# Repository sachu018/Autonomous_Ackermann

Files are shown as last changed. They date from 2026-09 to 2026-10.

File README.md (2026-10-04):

# Design, Real-Time Embedded Control & Autonomous Navigation for an Agricultural Ackermann Rover





[]()

> **Internship Project Report & Engineering Handover**  
> **Author:** Jagan J S (*Embedded Engineering Intern, Department of Electrical Engineering, IIT Palakkad*)  
> **Project:** *Aerial Dexterous Manipulators, Grasping and Transportation / Autonomous Agricultural Robotics*  
> **Documentation:** 📄 [Internship Report (PDF)](docs/Internship_Report.pdf) | 📘 [Handover Document (PDF)](docs/Handover_Document.pdf) | 📋 [Technical Handover Guide (MD)](docs/SUCCESSOR_HANDOVER_GUIDE.md)

---

## 📌 Executive Summary

Modern precision agriculture relies on autonomous unmanned ground vehicles (UGVs) to execute labour-intensive field tasks such as row monitoring, precision spraying, and selective weeding. 

This repository houses the complete electrical architecture, bare-metal C firmware, PCB design files, and Python autonomy stack developed to transform a legacy, open-loop BeagleBone Black differential-drive rover into a distributed, closed-loop **STM32F411 + Raspberry Pi 5 Ackermann-steering autonomous agricultural rover**.

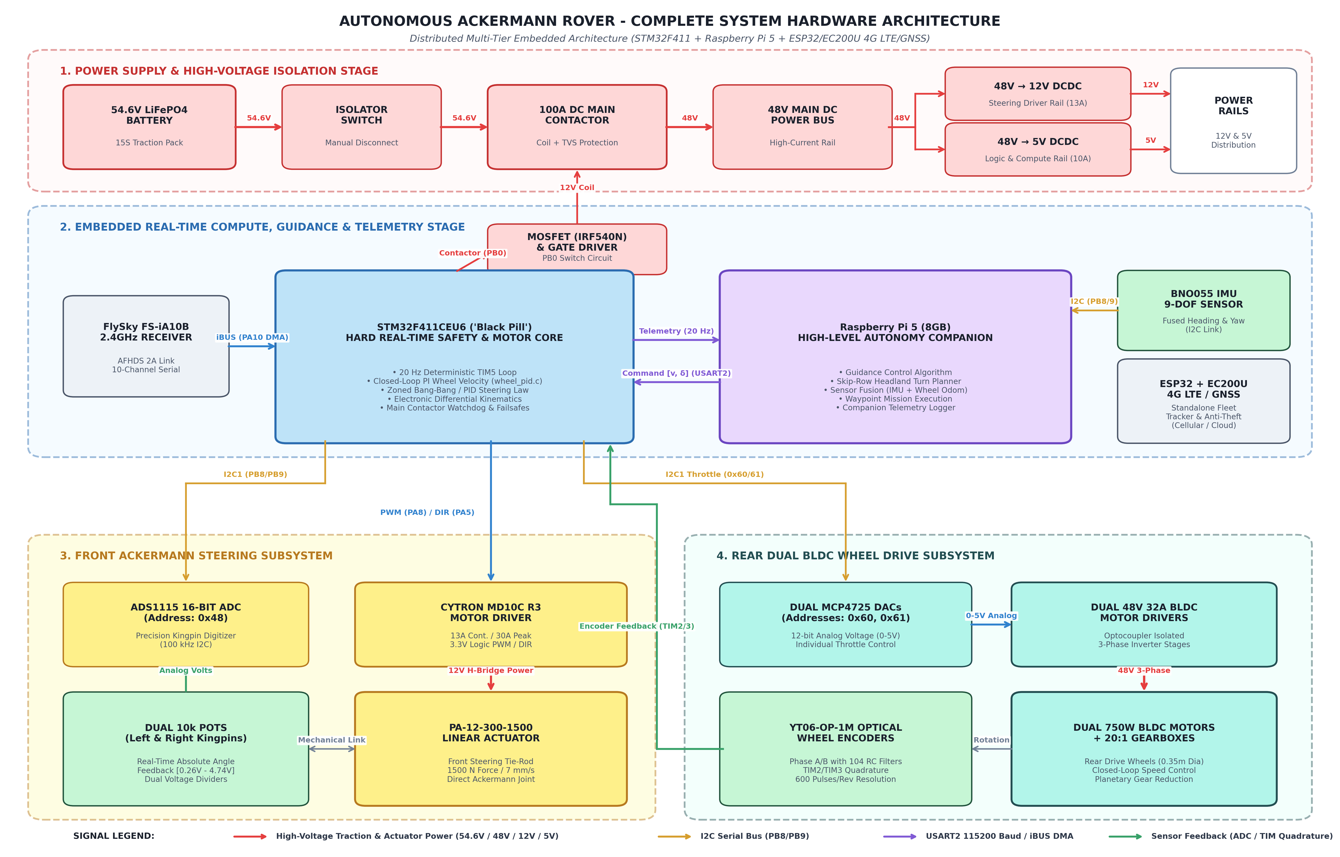
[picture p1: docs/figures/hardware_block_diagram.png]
System Architecture


---

## 🏗️ System Architecture

The vehicle is structured across a decoupled, multi-tiered hierarchy:

```
+-----------------------------------------------------------------------------+
|                             POWER SYSTEM (54.6V)                            |
|        54.6V LiFePO4 --> Isolator --> 100A DC Contactor --> 48V DC Bus      |
|                                         |                                   |
|                      +------------------+-------------------+               |
|                      |                                      |               |
|              48V -> 12V Buck                        48V -> 5V Buck          |
|              (Actuator & Driver)                    (Logic & RPi 5)         |
+-----------------------------------------------------------------------------+
                                       │
                                       ▼
+-----------------------------------------------------------------------------+
|                        HIGH-LEVEL COMPUTE & AUTONOMY                        |
|                                                                             |
|   +-----------------------+                    +------------------------+   |
|   |   Raspberry Pi 5      |<─── I2C1 (400k) ───| BNO055 9-DOF IMU       |   |
|   |   Autonomy Engine     |                    +------------------------+   |
|   |   • Stanley / Pure    |                                                 |
|   |     Pursuit Followers |                    +------------------------+   |
|   |   • Skip-Row Planner  |                    | 4G UGV Tracker (ESP32) |   |
|   |   • Odom / IMU Fusion |                    | • Quectel EC200U LTE   |   |
|   +-----------------------+                    | • Standalone Telemetry |   |
|               │                                +------------------------+   |
|               │ UART 115200 (USART2 Binary Protocol + DMA)                  |
|               ▼                                                             |
+-----------------------------------------------------------------------------+
                                       │
                                       ▼
+-----------------------------------------------------------------------------+
|                       REAL-TIME EMBEDDED CONTROL CORE                       |
|                                                                             |
|   +---------------------------------------------------------------------+   |
|   |                    STM32F411CEU6 ("Black Pill")                     |   |
|   |   • 20 Hz Deterministic Loop (TIM5 Hardware Timer)                  |   |
|   |   • Discrete PI Wheel Velocity Control (wheel_pid.c)                |   |
|   |   • Dual-Zone Linear Actuator Steering Control (actuator.c)         |   |
|   |   • Electronic Differential Geometry Computation                    |   |
|   |   • Contactor MOSFET Switch & 400ms Hard RF Failsafe Ladder         |   |
|   +---------------------------------------------------------------------+   |
|          │             │                 │                   │              |
+----------│-------------│-----------------│-------------------│--------------+
           │             │                 │                   │
  PWM/DIR (PA8/5)   I2C1 (0x48)      I2C1 (0x60/61)      TIM2/3 Quadrature
           │             │                 │                   │
           ▼             ▼                 ▼                   ▼
    +-------------+ +----------+    +---------------+   +------------------+
    | Cytron MD10C| | ADS1115  |    | Dual MCP4725  |   | YT06-OP-1M Optic |
    | Motor Driver| | 16-b ADC |    | 12-bit DACs   |   | Wheel Encoders   |
    +-------------+ +----------+    +---------------+   +------------------+
           │             ▲                 │                     ▲
           ▼             │                 ▼                     │
    +-------------+ +----------+    +---------------+            │
    | PA-12 Linear| | Dual 10k |    | Dual BLDC     |────────────┘
    | Actuator    | | Kingpin  |    | Motor Drivers |
    | (Steering)  | | Pots     |    | (48V 32A)     |
    +-------------+ +----------+    +---------------+
                                           │
                                           ▼
                                    +---------------+
                                    | Dual 750W BLDC|
                                    | 20:1 Gearbox  |
                                    +---------------+
```

---

## ⚙️ Mechanical & Kinematic Specifications

| Parameter | Symbol | Engineering Value | Firmware Reference |
| :--- | :---: | :--- | :--- |
| **Wheelbase** | $L$ | $0.850\text{ m}$ ($850\text{ mm}$) | `ROVER_WHEELBASE_M` |
| **Track Width** | $W$ | $0.800\text{ m}$ ($800\text{ mm}$) | `ROVER_TRACK_WIDTH_M` |
| **Wheel Radius** | $r$ | $0.175\text{ m}$ ($175\text{ mm}$) | `ROVER_WHEEL_RADIUS_M` |
| **Gearbox Reduction** | $G$ | $20:1$ Planetary Reduction | Motor-to-Axle Ratio |
| **Max Linear Velocity** | $v_{\text{max}}$ | $0.458\text{ m/s}$ ($1.65\text{ km/h}$) | `MAX_LINEAR_VELOCITY` |
| **Nominal Cruise Speed** | $v_{\text{cruise}}$ | $0.240\text{ m/s}$ ($0.86\text{ km/h}$) | Path tracking default |
| **Max Steering Angle** | $\delta_{\text{max}}$ | $\pm 45.0^\circ$ | `STEER_MAX_DEG` |
| **Minimum Turning Radius**| $R_{\text{min}}$ | $\approx 2.50\text{ m}$ | Non-holonomic steering limit |

---

## 🧩 Key Subsystems & Features

### 1. STM32 Bare-Metal Firmware (`Rover_closed_loop/`)
- **Deterministic 20 Hz Execution:** Managed via hardware timer `TIM5` interrupt for jitter-free control.
- **Dual-Zone Steering Control:** Combines full-speed slewing in large error zones with fine-grained PID in small error deadbands to eliminate linear actuator overshoot.
- **Electronic Differential:** Dynamically calculates individual wheel speeds during turns:
  $$v_L = v \left(1 - \frac{W}{2L} \tan\delta\right), \quad v_R = v \left(1 + \frac{W}{2L} \tan\delta\right)$$
- **Hardware Failsafe Ladder:** 400 ms timeout on iBUS/serial input; immediately drops throttle and disengages contactor if signal loss occurs.

### 2. Raspberry Pi 5 Autonomy Engine (`RPi_companion/`)
- **Stanley & Pure Pursuit Controllers:** Robust cross-track and heading error compensation for path tracking.
- **Agricultural Skip-Row Headland Planning:** Solves turning infeasibilities where crop row spacing ($1.4\text{ m}$) is narrower than the vehicle's minimum turning radius ($2.5\text{ m}$).

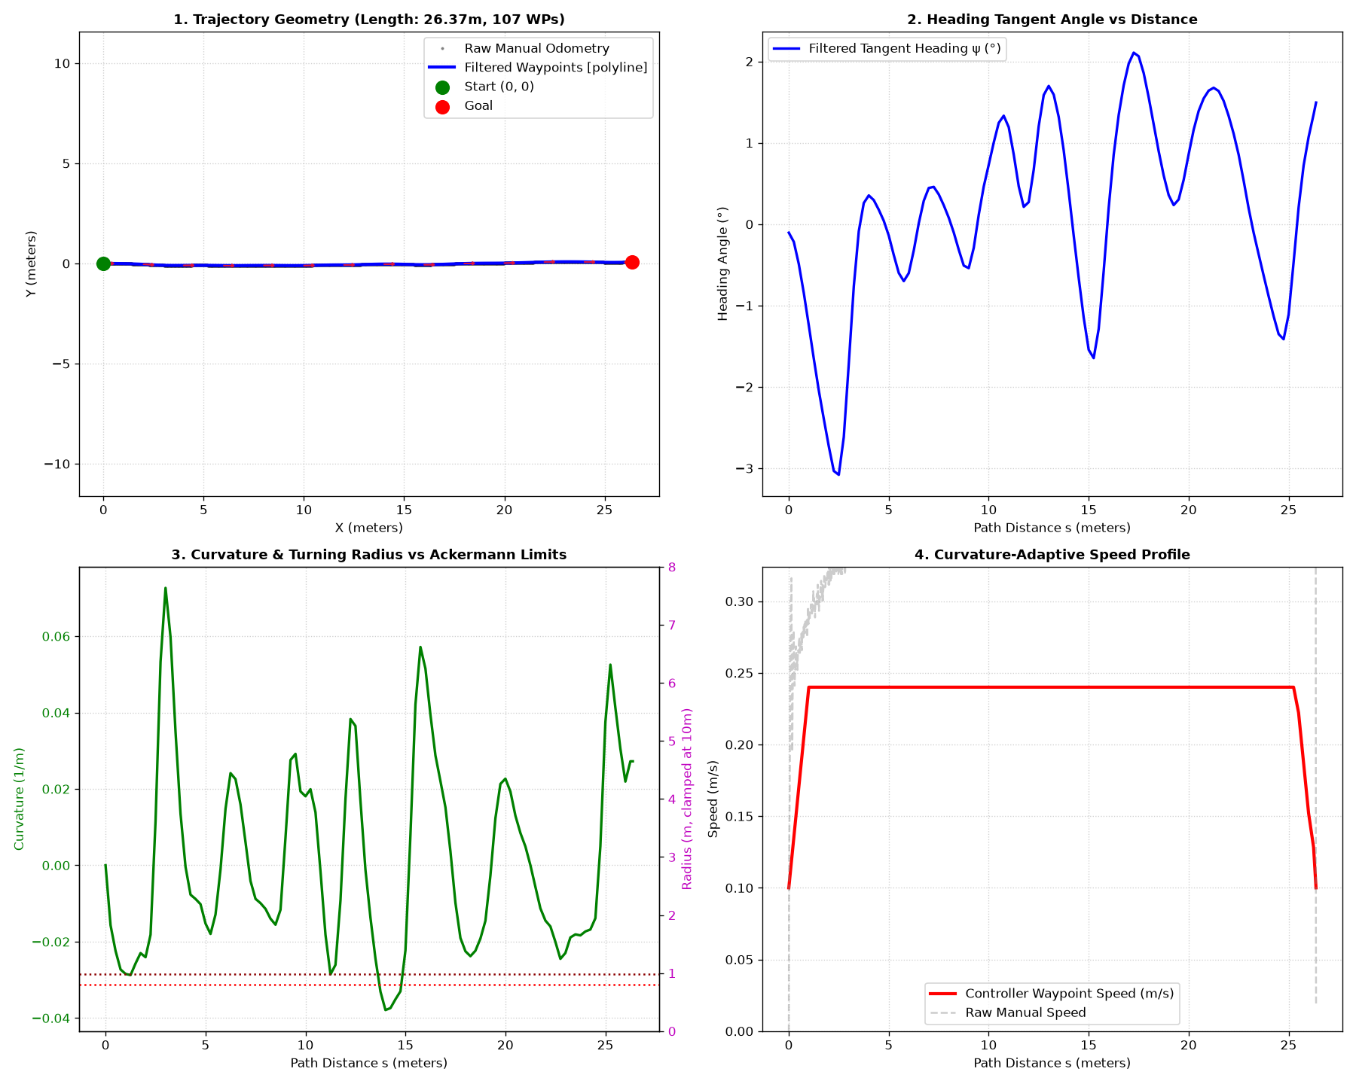
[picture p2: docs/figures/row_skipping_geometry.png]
Skip-Row Planning


### 3. Electrical & PCB Layout (`Hardware_KiCad/`)
- Custom schematic and 2-layer PCB layout incorporating optocouplers, RC snubber circuits, TVS diodes, and high-current copper pours.

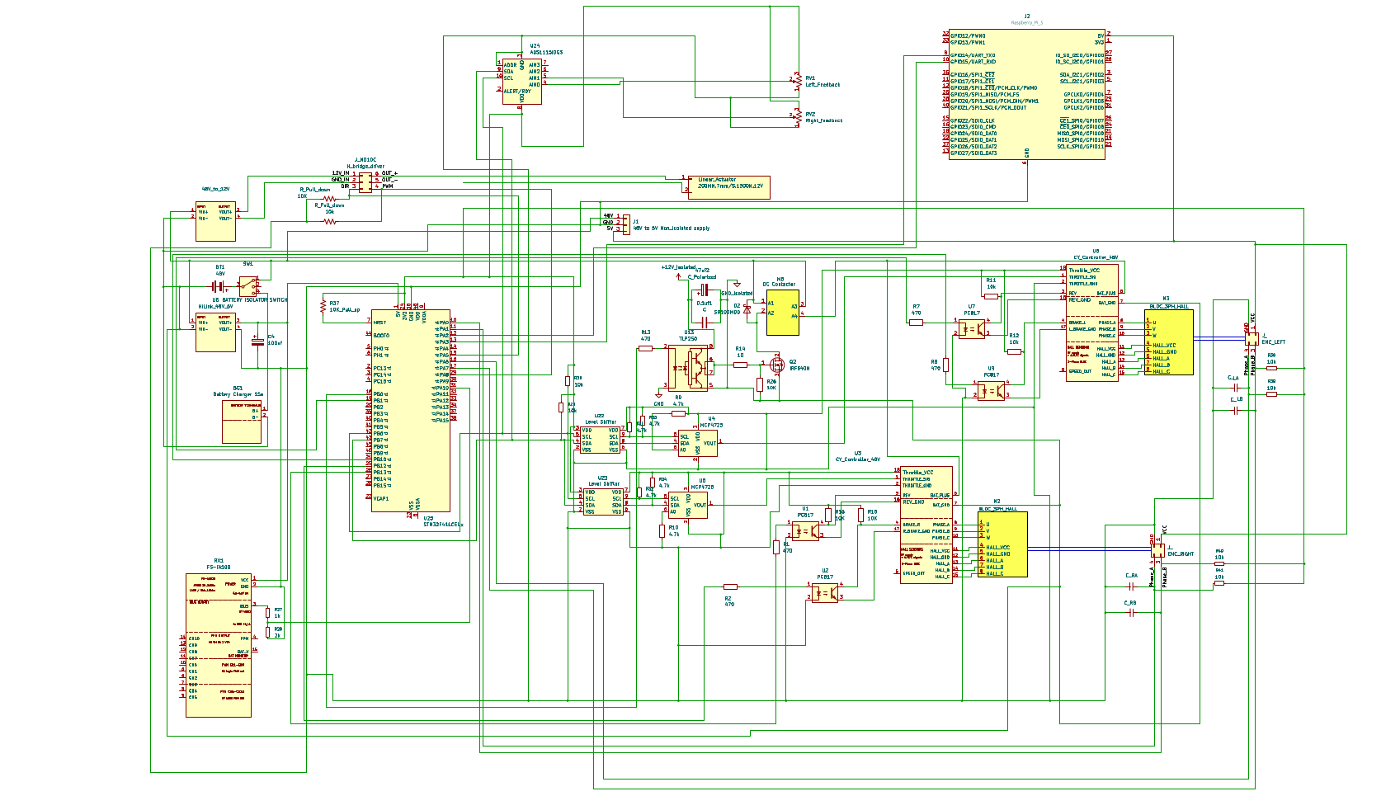
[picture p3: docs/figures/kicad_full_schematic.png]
Hardware Schematic


---

## 📁 Repository Structure

```
Autonomous_Ackermann/
├── docs/
│   ├── figures/                       ← Architectural & field benchmark figures
│   ├── Internship_Report.pdf          ← Full academic internship report (IIT Palakkad)
│   ├── Handover_Document.pdf          ← Comprehensive technical handover manual
│   └── SUCCESSOR_HANDOVER_GUIDE.md    ← Markdown successor engineering guide
│
├── Rover_closed_loop/                 ← Production STM32 Bare-Metal Firmware
│   ├── Core/
│   │   ├── Inc/                       ← Header files (wheel_pid.h, main.h, etc.)
│   │   └── Src/                       ← Source files (main.c, wheel_pid.c, actuator.c)
│   ├── Drivers/                       ← STM32 HAL and CMSIS Drivers
│   └── Rover_closed_loop.ioc          ← STM32CubeMX Project Configuration
│
├── RPi_companion/                     ← Raspberry Pi 5 Python Autonomy Stack
│   ├── ackermann_controller.py        ← Stanley & Pure Pursuit path tracking
│   ├── rpi_stm32_bridge.py            ← Fast binary UART serial bridge
│   ├── make_lawnmower_path.py         ← Boustrophedon grid coverage generator
│   └── make_skip_row_path.py          ← Agricultural headland skip-row planner
│
├── Hardware_KiCad/                    ← Complete KiCad v6 Schematics & PCB Layout
│   ├── kicad_setup.kicad_pro          ← KiCad Project File
│   ├── kicad_setup.kicad_sch          ← Full System Schematic
│   └── kicad_setup.kicad_pcb          ← 2-Layer PCB Board Layout
│
├── ESP32_uart_sniffer/                ← Diagnostic UART sniffer firmware
└── Documentations/                    ← Detailed engineering logs and notes
```

---

## 🚀 Getting Started

### Building STM32 Firmware
1. Open [`Rover_closed_loop/`](file:///home/tuf/Documents/REPORT/Autonomous_Ackermann/Rover_closed_loop) in **STM32CubeIDE** or build using `make` / `arm-none-eabi-gcc`.
2. Flash via ST-Link V2 using STM32CubeProgrammer or OpenOCD:
   ```bash
   st-flash write build/Rover_closed_loop.bin 0x8000000
   ```

### Running Raspberry Pi 5 Autonomy
1. Connect Raspberry Pi 5 UART (`/dev/ttyAMA0`) to STM32 `USART2` (`PA2`/`PA3`).
2. Run the navigation controller:
   ```bash
   cd RPi_companion
   python3 ackermann_controller.py --controller stanley --path paths/lawnmower_pattern.csv
   ```

---

## 📜 Citation & Credits

* **Author:** Jagan J S
* **Affiliation:** Department of Electrical Engineering, Indian Institute of Technology Palakkad
* **Supervision:** *Aerial Dexterous Manipulators, Grasping and Transportation* Lab / OSDISG Research Group

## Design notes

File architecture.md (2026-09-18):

# Architecture Plan & System Design — Closed-Loop Ackermann Steering

## 1. System Overview & Platform Context
The Agriculture Rover is a robotic platform powered by the **STM32F411CEU6 (Black Pill)** microcontroller (running bare-metal C with STM32Cube HAL at 100 MHz).

The closed-loop Ackermann version operates in the **`Rover_closed_loop/`** project directory, leaving the original open-loop `Rover/` codebase untouched as a verified fallback.

### Hardware Interconnects & Pin Allocation
| Pin | Function | Peripheral / Mode | Purpose |
|---|---|---|---|
| **PA10** | iBUS RX | USART1_RX (DMA2 Stream 2) | FlySky FS-iA6B RC receiver stream (115200 baud) |
| **PA9** | Telemetry TX | USART1_TX (Direct register DR) | ESP32 telemetry bridge (115200 baud) |
| **PA8** | Actuator PWM | TIM1_CH1 (PWM Generation) | MD10C speed input (0–100% duty) |
| **PA5** | Actuator DIR | GPIO Output (`Actuator_DIR`) | MD10C direction input (HIGH=Extend/Left, LOW=Retract/Right) |
| **PB6** | I2C1 SCL | I2C1 (100 kHz Standard Mode) | Shared bus: MCP4725 DACs (0x60, 0x61) + ADS1115 ADC (0x48) |
| **PB7** | I2C1 SDA | I2C1 (100 kHz Standard Mode) | Shared bus: MCP4725 DACs (0x60, 0x61) + ADS1115 ADC (0x48) |
| **PB0** | Contactor | GPIO Output PP | Main motor controller power relay |
| **PB1** | Rev Left | GPIO Output PP | Left motor controller reverse direction |
| **PB10** | Brake Left | GPIO Output PP | Left motor controller brake |
| **PB12** | Brake Right | GPIO Output PP | Right motor controller brake |
| **PB13** | Rev Right | GPIO Output PP | Right motor controller reverse direction |
| **PA0 / PA1** | Encoder L | TIM2 (32-bit, TI12 Mode) | Left wheel shaft optical encoder |
| **PA6 / PA7** | Encoder R | TIM3 (16-bit, TI12 Mode) | Right wheel shaft optical encoder |
| **PC13** | Status LED | GPIO Output PP (Active-LOW) | Onboard diagnostic fault indicator |
| **PA2** | RPi TX | USART2_TX | → RPi5 Pin10 / GPIO15 (RXD) — command/feedback link, firmware flashed, RPi side not yet wired/tested |
| **PA3** | RPi RX | USART2_RX | ← RPi5 Pin8 / GPIO14 (TXD) — command/feedback link, firmware flashed, RPi side not yet wired/tested |

---

## 2. Decoupled Closed-Loop Control Architecture

The system decouples steering from propulsion to prevent tire scrubbing and guarantee kinematic accuracy:

```
[RC Joystick X] ──→ Target Steering Angle δ_target (−45° to +45°)
                             │
                             ▼
[Steering Loop] ────→ Steer PID (Derivative-on-Measurement) ──→ MD10C (PA8/PA5) ──→ Linear Actuator
                             ▲                                                              │
                             │                                                              ▼
                      Measured Angle δ_actual ◄── ADS1115 (0x48, AIN0/AIN1) ◄── 2× 10k Potentiometers
                             │
                             ▼
[Propulsion Loop] ──→ Ackermann Electronic Differential (tan(δ)) ──→ Rear Wheel DACs (Left/Right)
                             ▲
                             │
[RC Joystick Y] ───→ Base Speed V_base
```

### 2.1 Steering Feedback Loop (`ads1115.c` & `actuator.c`)
- **ADS1115 ADC:** Reads Left Wheel Angle (`AIN0`) and Right Wheel Angle (`AIN1`) over I2C1 at 860 SPS (~1.16 ms conversion).
- **Fault Debounce:** Uses `STEER_FAULT_THRESHOLD = 5` consecutive bad reads before declaring a sensor failure; transient 1-tick glitches maintain the previous angle without stalling the actuator.
- **Actuator Full-Speed Directional Control:**
  - Because the linear actuator moves at ~7 mm/s max speed, it runs at **100% full speed** whenever outside the deadband ($\pm 0.5^\circ$), eliminating unnecessary speed throttling.
  - When within $\pm 0.5^\circ$ of target angle, PWM stops (`0%`) and the linear actuator mechanically holds position.

### 2.2 Propulsion & Differential Loop (`ackermann.c`)
- **Kinematic Radius:** Uses exact bicycle model turning radius about the rear axle center:
  $$R_{\text{rear}} = \frac{W_b}{\tan(\delta)}$$
- **Wheel Speeds:**
  $$V_{\text{right}} = V_{\text{base}} \left(1 + \frac{L_t}{2 R_{\text{rear}}}\right), \quad V_{\text{left}} = V_{\text{base}} \left(1 - \frac{L_t}{2 R_{\text{rear}}}\right)$$
- **Standstill Pivot Mode:** Full steering deflection withholds drive until wheels swing past 80% of target lock ($36^\circ$), then locks the inner rear wheel at 0 RPM while the outer rear wheel crawls forward at ~7.5 RPM to pivot around the inner tire.

---

## 3. Autonomous Integration — Raspberry Pi Companion Computer (Planned)

**Goal:** restore the autonomous waypoint-following capability the platform had on the BeagleBone Black (see `Documentations/Rover_study.md` §13 and `Old_files/UGV_closed/`), but re-architected around the STM32 as a real-time actuation server rather than the BBB's single-process "brain."

### 3.1 Division of Responsibility

| Layer | Runs on | Responsibility |
|---|---|---|
| **Guidance & sensing** | Raspberry Pi | IMU + RTK GNSS fusion, localization (UTM conversion), path/waypoint management, guidance law (P/ISMC → target `V`, `δ`) |
| **Real-time actuation** | STM32F411 | Steering PID/bang-bang + ADS1115 feedback, Ackermann electronic differential, encoder feedback, contactor/arming, all existing RC failsafes |

This is a deliberate inversion of the old BBB architecture, where the BBB itself ran guidance *and* drove the DACs/GPIO directly, and the RPi was only a passive RTK data source over TCP (`Old_files/UGV_closed/rtk_receiver.py`). Here, the RPi becomes the guidance brain; the STM32 keeps owning every safety-critical/real-time function it already owns today, and simply gains a second command source (UART from the RPi) alongside the existing RC iBUS source.

### 3.2 Physical Link

STM32 **USART2** (PA2 TX / PA3 RX) ↔ Raspberry Pi 5 primary UART (`GPIO14`/Pin8 TXD, `GPIO15`/Pin10 RXD), GND common. Configured in `Rover.ioc` and generated — see §3.6.

Cross-connect (TX→RX both ways):
| STM32 | RPi5 |
|---|---|
| PA3 (USART2_RX) | Pin8 / GPIO14 (TXD) |
| PA2 (USART2_TX) | Pin10 / GPIO15 (RXD) |
| GND | GND (any GND pin) |

**✅ RPi5 setup complete and verified working** (link confirmed end-to-end, 20 Hz, zero corruption). Three things were needed, not just the console — see §3.6/§3.8 for the full story: (1) disable the login console on `GPIO14`/`GPIO15`, (2) disable onboard Bluetooth (`dtoverlay=disable-bt`, it silently claims the same UART), (3) `enable_uart=1` (the actual root cause of an extended debugging session — without it the pins are never muxed to UART at the hardware level at all).

### 3.3 Mode Arbitration

- **SWD** (unchanged): arms/disarms the contactor, exactly as today.
- **SWB** (repurposed): was the 2-position reverse-speed-cap switch (`SWB_SPEED_LOW/HIGH` = 60%/100%); becomes a pure **MANUAL / AUTO** command-source select. Reverse-speed-cap feature is dropped — reverse runs at the same cap as forward once this lands (see scratchpad.md).
- When armed **and** SWB = MANUAL → command source is RC iBUS (`Xn`, `Yn`), as today.
- When armed **and** SWB = AUTO → command source is the UART link from the RPi (target steering angle `δ_target`, target speed `V_target`), fed into the same downstream steering PID / Ackermann differential the RC path already uses.

### 3.4 UART Protocol (implemented in firmware, not yet hardware-tested)

20 Hz, binary, fixed-size frames, matching the main loop's own rate.

**Command frame — RPi → STM32:**
| Field | Type | Meaning |
|---|---|---|
| header | `0xAA 0x55` | frame sync |
| steer_target | `int16` (°×100) | target steering angle, −45.00° to +45.00° |
| speed_target | `int16` (mm/s) | target linear speed, signed (+fwd / −rev) |
| seq | `uint8` | rolling counter — reserved for detecting a stalled-but-connected RPi (repeated seq = link up, RPi logic frozen); parsed but **not yet acted on** in `rpi_link.c` |
| checksum | `uint8` | XOR of all preceding bytes, same spirit as the existing iBUS checksum on PA10 |

**Feedback frame — STM32 → RPi:**
| Field | Type | Meaning |
|---|---|---|
| header | `0xBB 0x66` | frame sync |
| angle_L, angle_R | `int16` each (°×100) | measured steering angle per wheel (ADS1115) |
| rpm_L, rpm_R | `int16` each (RPM×10) | encoder wheel speed |
| status | `uint8` bitfield | armed / steer-fault / actuator-fault / contactor state |
| checksum | `uint8` | |

### 3.5 Failsafe

New `AUTO_UART_TIMEOUT_MS` (~300 ms, same order as the existing 400 ms RC timeout). If SWB = AUTO and no valid command frame arrives within that window, the STM32 forces `BRAKE` — same behavior class as RC signal loss today — regardless of the last command received. Flipping SWB back to MANUAL always hands control back to the RC sticks immediately, independent of UART link state.

**Not yet decided:** whether stick deflection should also force a manual takeover while SWB is still in AUTO (the old BBB `safety.py` did this at a 15% threshold). Left open for now — SWB is the sole arbiter until/unless this is explicitly added.

### 3.6 RPi-Side Software (`RPi_companion/`)

New top-level directory for all Raspberry Pi 5 Python code — parallel to `Rover_closed_loop/` and `Documentations/`. Started with the IMU driver; guidance/localization/UART-client modules land here as they're built.

**Hardware:** DFRobot Fermion BNO055 9-axis IMU, I2C1 on the RPi5's 40-pin header — VCC→Pin1 (3V3), SDA→Pin3 (GPIO2), SCL→Pin5 (GPIO3), GND→Pin6. Default I2C address `0x28` (ADR pin floating/low).

| File | Purpose |
|---|---|
| `RPi_companion/requirements.txt` | `adafruit-blinka`, `adafruit-circuitpython-bno055` — same library family the old BBB stack used (`Old_files/dev_bak/test_imu.py`), continued here since Blinka now supports the Pi 5 |
| `RPi_companion/imu.py` | `IMU` driver class — `board.I2C()` + `adafruit_bno055`, returns an `IMUData` sample (heading/roll/pitch deg, gyro_z rad/s, accel_x/y m/s², calibration status, `valid`). Fault handling deliberately mirrors `ads1115.c` on the STM32 side: holds the last valid sample across transient I2C glitches, only flips `valid=False` after `IMU_FAULT_THRESHOLD` (5) consecutive bad reads. Supports optional calibration-offset preload via `IMU_CALIBRATION_OFFSETS` |
| `RPi_companion/test_imu.py` | Live readout script — **run this first** after wiring, before trusting `imu.py` in anything else, to confirm hardware/wiring/address are correct |
| `RPi_companion/calibrate_imu.py` | Waits for full calibration (Sys/Gyro/Accel/Mag all = 3), then reads back and prints the sensor's internal offset registers in a form that pastes directly into `imu.py`'s `IMU_CALIBRATION_OFFSETS` |
| `RPi_companion/uart_link.py` | `STM32Link` driver for the STM32 UART link (counterpart to `rpi_link.c`) — background thread parses feedback frames (header-scan + checksum, no hardware IDLE-line equivalent on this side), exposes `read()`/`send_command()`. Frame formats hand-copied from `rpi_link.c`'s header comment; the two sides have no shared schema file, keep them in sync manually if the protocol ever changes |
| `RPi_companion/check_stm32_link.py` | Connectivity check — sends neutral (0,0) command frames, reports feedback frame rate/checksum failures/status bits. Sending is inert while SWB=MANUAL; proves the RX half (STM32→RPi) directly, the TX half only indirectly (see the script's own header comment for the caveat and why) |
| `RPi_companion/read_encoders.py` | Passive live readout of wheel RPM + steering angle from the feedback frame — sends nothing, safe to run anytime including during manual driving |
| `ESP32_uart_sniffer/ESP32_uart_sniffer.ino` | Read-only ESP32 tap on STM32 `PA2` (USART2_TX) only — isolates whether the STM32 is physically transmitting feedback frames, independent of the RPi's software/wiring entirely. Same one-way-bridge safety rule as the existing PA9 debug bridge: never connect its TX pin to `PA3` while the RPi is also wired there (two transmitters on one line). See §3.8 for the diagnostic session that motivated this. |

**Setup checklist (on the RPi5 itself):**
- [x] Disable the Linux serial console on `GPIO14`/`GPIO15` (Pin8/Pin10) — done directly (not via `raspi-config`, which wasn't present in this Debian 13 "trixie" image): `systemctl disable --now serial-getty@ttyAMA10.service` + removed `console=serial0,115200` from `/boot/firmware/cmdline.txt`. Confirmed `inactive`/`disabled` and non-regenerating after a reboot (the unit is runtime-generated from the `console=` kernel parameter, so removing that parameter is what actually makes it permanent, not the `disable` alone).
- [x] Disable onboard Bluetooth (`dtoverlay=disable-bt`) — it silently claims the same UART as GPIO14/15 at boot, independent of the console-getty fix above. **Required, not optional, for this UART to work.** Disables BT on this Pi permanently (not used elsewhere in this project).
- [x] Add `enable_uart=1` to `config.txt` — **this was the actual root cause of the "zero bytes" debugging session** (§3.8): without it, GPIO14/15 are never switched into UART alternate-function mode at the hardware level, even though `/dev/serial0` exists as a device node. Verify with `pinctrl get 14,15` → expect `GPIO14 = TXD0`, `GPIO15 = RXD0` (not `none`).
- [x] Confirm I2C1 is enabled — uncommented `dtparam=i2c_arm=on` in `/boot/firmware/config.txt`, rebooted. Confirmed live: `i2cdetect -l` shows `i2c-1` ("Synopsys DesignWare I2C adapter"). `board.I2C()` correctly auto-detects `RASPBERRY_PI_5` with `SCL=GPIO3`/`SDA=GPIO2`.
- [ ] `i2cdetect -y 1` with the sensor attached — confirm a device shows at `0x28` (or `0x29` if the ADR pin is strapped high; pass `address=0x29` to `IMU()` if so). **Blocked: IMU not physically connected this session** (Pi was on the bench, no peripherals).
- [x] `python3 -m venv ~/rover-venv && source ~/rover-venv/bin/activate && pip install -r RPi_companion/requirements.txt` — needed two extra system packages first, not obvious from the Python package alone: `sudo apt-get install -y swig liblgpio-dev` (the `lgpio` GPIO backend has no prebuilt wheel for this OS/arch and fails to compile/link without them). Documented in `requirements.txt`'s header comment.
- [x] Deployed `RPi_companion/` to `~/RPi_companion` on the Pi.
- [x] `python3 test_imu.py` with nothing attached — confirmed it fails cleanly (`No I2C device at address: 0x28`, exit 1, no hang/crash) rather than silently returning fake data. This is as far as verification can go without the sensor.
- [ ] Re-run `test_imu.py` once the BNO055 is physically reconnected — confirm heading/roll/pitch update sensibly as the board is moved, `valid=OK`.
- [ ] `python3 calibrate_imu.py` — run the still/6-orientation/figure-8 ritual, get all four calibration values to 3, record the printed offsets in scratchpad.md and paste into `imu.py`.

**Not reused from the old BBB rig:** the saved `bno055_calibration.json` offsets (`accel[0,0,0]`, `gyro[-2,0,1]`, `mag[111,-187,-126]`) — those are specific to that sensor's old physical mounting and magnetic environment, not this one. Fresh calibration required.

### 3.7 Firmware File Reference (Phase 5)

| File | Purpose |
|---|---|
| `Core/Inc/rpi_link.h`, `Core/Src/rpi_link.c` | USART2 DMA+IDLE framing, command parse, feedback send — mirrors `ibus.c`'s role for USART1 |
| `Core/Inc/ibus.h`, `Core/Src/ibus.c` | Modified: `SWB` now decodes to `IBUSData_t.auto_mode` via `_SwbToAuto()`; `rev_speed_pct` fixed at `1.0f` |
| `Core/Inc/config.h` | Modified: SWB section rewritten, `SWB_SPEED_LOW/HIGH` removed, new RPi link protocol/timeout constants added |
| `Core/Inc/ackermann_config.h` | Modified: added `AUTO_SPEED_DEADBAND_MS` |
| `Core/Inc/ackermann.h`, `Core/Src/ackermann.c` | Modified: added `Ackermann_RunAuto()` |
| `Core/Src/main.c` | Modified: reads `RPiCmd_t` each tick, branches on `rc.auto_mode`, sends feedback frame every tick; also had missing includes restored (see scratchpad.md) |
| `Core/Src/stm32f4xx_it.c` | Modified: `USART2_IRQHandler` now calls `RPiLink_IdleCallback()` on the IDLE flag |
| `Rover.ioc` | Modified: `USART2` peripheral (PA2/PA3), `DMA1_Stream5` RX request, associated NVIC entries |

**Status: RESOLVED — link fully verified working end-to-end.** Rover on a jack for bench testing; `check_stm32_link.py` shows a steady 20.0 frames/s with zero checksum failures, `read_encoders.py` shows live, sane angle/RPM data. See §3.8 for the root cause and the debugging trail that found it.

### 3.8 UART Link Debugging Session — RESOLVED

**Symptom:** first end-to-end test (`RPi_companion/check_stm32_link.py`) found zero bytes arriving at the RPi, confirmed at the raw-byte level (bypassing all app parsing).

**Ruled out along the way, by code audit + physical checks** (STM32 firmware code, `check_stm32_link.py`'s own logic, a stale `.elf`, GPIO pin conflicts, a boot-time `Error_Handler()` hang, and unbounded I2C calls in the boot path) — none of these were the cause. `ESP32_uart_sniffer/` (a read-only tap directly on STM32 `PA2`, isolated from the RPi entirely) confirmed the STM32 **was** transmitting correctly the whole time, and the user independently re-confirmed the physical wiring was correct — which narrowed the fault to the RPi's own OS/config, exactly as the user suspected.

**Root cause — two stacked problems on the RPi side:**
1. **Bluetooth was silently claiming the UART.** `dmesg` showed `hci_uart_bcm serial0-0: ...` — the Pi 5's onboard Bluetooth shares the same physical UART as GPIO14/15. Freeing the login console (§3.6's original setup) wasn't sufficient; Bluetooth's own boot-time attach process re-claimed the port independently, leaving it at 9600 baud with the HCI line discipline attached instead of a plain raw serial port. Fixed with `dtoverlay=disable-bt` in `/boot/firmware/config.txt` — **this permanently disables Bluetooth on this Pi**, an accepted trade-off since BT isn't used anywhere in this project.
2. **The real root cause: `enable_uart=1` was never set.** Even after fixing Bluetooth, zero bytes persisted. `pinctrl get 14,15` (RP1's pin-mux inspection tool) revealed `GPIO14 = none`, `GPIO15 = none` — the physical pins were never switched into UART alternate-function mode at the hardware level, despite `/dev/ttyAMA10` existing as a kernel device node and a `serial-getty` unit having appeared to run on it previously. **A device node existing, or even a getty being "active," does not prove the GPIO pins are actually muxed to the peripheral** — that assumption is what cost the most debugging time. Fixed by explicitly adding `enable_uart=1` to `config.txt`; confirmed after reboot via `pinctrl get 14,15` → `GPIO14 = TXD0`, `GPIO15 = RXD0`.

**Verification after both fixes:** raw `cat /dev/serial0` (with baud explicitly forced to 115200 via `stty`, since `cat` doesn't set it itself) showed clean, correctly-checksummed feedback frames. `check_stm32_link.py` then confirmed the full application-layer path: steady 20.0 frames/s, zero bad frames, `ARMED=Y RC_OK=Y`. `read_encoders.py` confirmed live sane data (`rpm_L`/`rpm_R` = 0.00, correct with the rover on a jack; `angle_L≈+39°` with normal jitter).

**One new observation, not yet investigated:** `angle_R` reads a rock-steady `-45.00°` with zero jitter, unlike `angle_L` which shows normal small ADC noise. Either the right wheel is genuinely sitting at full lock, or that channel is saturating/clamping. Not urgent (`STEER_FAULT` reports healthy) but worth checking against the physical wheel position next time someone's at the rover.

**Lesson for future RPi UART/GPIO work:** verify pin mux directly with `pinctrl get <pin>` before trusting a device node's existence or a systemd unit's "active" status as proof the hardware is actually configured — this applies to any future GPIO-peripheral wiring on this Pi, not just this UART.

### 3.9 Guidance Stack Design (No RTK — Dead Reckoning Only)

Studied `Old_files/dev_bak/`'s BBB-era encoder+IMU-only autonomous scripts (`ugv_p_waypoint.py`, `ugv_pid_waypoint.py`, `ugv_p_circle.py`/`_eight.py`/`_lawnmower.py`/`_lawnmower1.py`, and the 9-axis variant) before designing this — they're the closest prior art to what this rover needs, since it has no RTK wired to the RPi either. Key findings from that study, and the design decisions built on them:

**How the BBB system worked:** encoder ticks → distance traveled; BNO055 IMU's own fused Euler heading (not integrated from wheel odometry) → absolute-ish yaw. Position: `x += d·cos(yaw); y += d·sin(yaw)`. An outer P or PID loop (`ugv_p_*.py` vs `ugv_pid_*.py` — same skeleton, differ only in whether the outer loop has an I/D term) turned distance-to-goal and heading-error into linear/angular velocity, converted to differential wheel RPM, closed by an inner PI loop on encoder RPM. All of `waypoint`/`circle`/`eight`/`lawnmower` variants share one identical waypoint loader — **the pattern shape lived entirely in which CSV was loaded, not in the script.** The circle/eight/lawnmower CSVs themselves no longer exist anywhere in the backup.

**Chassis constants matched ours exactly:** `a=0.175` (wheel radius), `d=0.30` (half-track) are `WHEEL_RADIUS_M`/`TRACK_WIDTH_M/2` from our own `config.h` — but that geometry is for **differential drive**; this rover is Ackermann, so the low-level V,W→wheel-RPM conversion and the BBB's motor/DAC/PI-speed-loop code don't transfer. The dead-reckoning math and the outer guidance *concept* do.

**Coordinate frame — compass-referenced, not start-relative.** Local Cartesian meters (no lat/lon/UTM anywhere), heading 0° locked to a fixed IMU compass reading — captured exactly once, the first time `odometry.py` reads the IMU (in practice: whichever way the rover is pointed when `mission.py` is *launched*), reused for every mission run within that script's lifetime. **Position** `(0,0)` resets on every SWB MANUAL→AUTO rising edge (each mission starts from wherever the rover currently is), but **heading does not re-lock there** — see scratchpad.md Mistake 11, an actual bug where an earlier version re-locked heading on every restart too, silently defeating the entire point of choosing compass-referenced over start-relative (a pattern would have faced a different real-world direction on every restart). Caught by the user asking a clarifying question, not by the original smoke test.

**Algorithm — Pure Pursuit, not heading-error P/PID.** The BBB's `W`-based steering doesn't map onto Ackermann (no direct angular-velocity actuator, only a steering angle). Pure Pursuit's lookahead-point geometry outputs a steering angle directly (`δ = atan(2·L·sin(α)/Ld)`), which drops straight into `uart_link.py`'s `send_command(steer_target_deg, speed_target_ms)` with no intermediate conversion.

**Tuned parameters, final:**

| Parameter | Value | Basis |
|---|---|---|
| Lookahead `Ld` | 0.8 m | Same as old system's `LOOK_AHEAD_DIST` |
| Waypoint spacing — straight | 1.0 m | Matches old `waypoints_1m.csv` convention |
| Waypoint spacing — curves | 0.3 m | User decision |
| Lawnmower row spacing | 1.0 m | User decision — see finding below |
| Waypoint-reached / mission-end threshold | 0.25 m | Tightened from the old system's 0.4m (RTK-noise-tuned; ours is dead-reckoning-drift-tuned, and our path itself is denser) |
| Heading-error bound (speed shaping) | 25° | Kept as old default, deferred to field tuning |
| Speed-shaping cos floor | 0.2 | Kept as old default (`V *= max(0.2, cos(bounded heading error))`), deferred to field tuning |
| Cruise speed | 0.2 m/s (placeholder) | **Not yet decided by the user** — conservative default, flagged for review |

Since curve spacing (0.3m) is narrower than `Ld` (0.8m) — the opposite relationship the old system had (`Ld` narrower than its 1.0m spacing) — the lookahead point on curves routinely spans several waypoints at once. Implemented proper circle-path intersection search (`guidance.py`) rather than porting the old segment-local projection code, which assumed the lookahead point stays within the current segment.

**⚠️ Physical-feasibility finding: lawnmower turn radius.** A clean single-arc U-turn at 1.0m row spacing needs a 0.5m turn radius. This chassis's actual minimum (wheelbase 0.8m, 45° max lock) is **0.8m** — tighter than the vehicle can steer. `waypoints.py`'s `_semicircle_turn()` catches this (compares against `MIN_TURN_RADIUS_M`) and uses 0.8m instead, landing the turn **1.6m over, not 1.0m**, printing a warning when it does. Confirmed via smoke test: a 4-row/3-turn lawnmower pattern ends up offset by exactly 4.8m (3×1.6m). A true 1.0m in-spacing turn would need a reverse/three-point-turn maneuver — not implemented, would need explicit sizing before building. **Not yet decided by the user** whether this is acceptable or worth building the tighter-turn version.

**File reference:**

| File | Purpose |
|---|---|
| `RPi_companion/rover_config.py` | Shared tunables — mirrors STM32 `ackermann_config.h`/`config.h` geometry constants, plus all the guidance parameters above. No shared header between Python and C; kept in sync by hand |
| `RPi_companion/waypoints.py` | Pattern generators (straight/rectangle/circle/lawnmower) + CSV I/O, pure geometry, no hardware access |
| `RPi_companion/odometry.py` | Dead-reckoning `Pose` estimator — fuses `imu.py` heading + STM32 encoder feedback |
| `RPi_companion/guidance.py` | `PurePursuit` controller — `Pose` + path in, `(steer_target_deg, speed_target_ms)` out |
| `RPi_companion/path_prompts.py` | Shared `input()` helper (float/int prompts with retry-on-bad-input) for the `make_*_path.py` scripts — not a program on its own |
| `RPi_companion/make_straight_path.py`, `make_rectangle_path.py`, `make_circle_path.py`, `make_lawnmower_path.py` | Interactive path generators — prompt for that shape's dimensions, save to `paths/<shape>_<dims>.csv`, print the exact `mission.py --csv ...` command to run it. One CSV-generation concern each, thin wrappers over `waypoints.py` |

**Status:** `mission.py` built, deployed, and **now driven under SWB=AUTO for the first time** — two real straight-line field tests (`mission_20260911_113236`, `_114042`). Every run auto-archives both the path used and a 31-column telemetry log to `~/RPi_companion/logs/` — this logging is what made the following diagnosis possible at all.

### 3.10 First AUTO Field Test — Diverged, Root-Caused, Two Fixes Applied

**Symptom** (user's report): "initially it went straight later turning." Both runs tracked well for the first ~10-12m, then spiraled into a growing steering oscillation — run 1 swung through ~50° of real heading change before happening to re-approach the final waypoint and finish; run 2 diverged further (reached yaw ≈ -156°, essentially backward) before the log ends. Full analysis in scratchpad.md (Mistakes 13/14); summary:

| Cause | Detail | Fix |
|---|---|---|
| **Bug 1 — lookahead search regression** | The "search one segment behind the cursor" logic added to fix the mission-start bug (§3.9) returned the FIRST valid Ld-circle intersection, not the furthest-along one. Near a waypoint-advance boundary, the behind-segment can have its own valid but BACKWARD intersection — hand-verified on a captured glitch: behind-segment gave path-progress 6.02, the correct forward segment gave 7.57. Caused two single-tick spikes (`alpha` briefly hitting -172°/-159°) per run. | `_find_lookahead_point()` now scans every candidate segment and keeps whichever has the greatest cumulative path progress. Regression-tested by replaying the exact captured scenario. |
| **Bug 2 — actuator lag vs. controller's implicit fast-response assumption** | The linear actuator moves at a fixed slow rate (~7mm/s bang-bang, no proportional speed). Pure Pursuit recomputes a full-authority target every 50ms with no model of how fast the actuator can move. Logged: `steer_cmd=-34.0°` while the *actual measured* steering angle was only `-9.7°` at the same tick — a chronic, large lag. Since the rear differential drives off the *actual* (lagging) angle, the rover kept following an old heading while the controller — seeing the resulting position error — demanded ever-larger corrections. **A genuine control-loop instability, not a simple mistuning.** | Not directly fixed — see below. |

**User's own diagnosis was the right call:** "if the error is increasing, the speed should reduce" is a legitimate, well-targeted mitigation for Bug 2 specifically — less distance covered per second gives the slow actuator more real time to catch up per meter of required heading change. While implementing it, found the speed law was **barely responsive at all**: it reused `YAW_BOUND_DEG` (25°, meant only for smoothing the *steering* law) as its own error input, and `cos(25°)=0.906` capped any possible speed reduction at ~9% — explaining why logged speed stayed ~0.18–0.20 m/s almost the entire time, even while `alpha` hit 157°.

**Speed law rebuilt** with independent thresholds:

| Parameter | Value |
|---|---|
| `CRUISE_SPEED_MPS` | 0.20 → **0.12** (felt too fast in the field, per report) |
| `MIN_SPEED_MPS` | 0.05 → **0.06** (small extra margin above the STM32's 0.03 brake deadband) |
| `SPEED_ALPHA_FULL_DEG` | **60°** (new — heading error at which speed bottoms out) |
| `SPEED_CTE_FULL_M` | **0.8** = `LOOKAHEAD_M` (new — cross-track error at which speed bottoms out) |
| `MIN_SPEED_FACTOR` | **0.3** (new — floor fraction of target speed even at max error, so it creeps rather than stops) |

Speed = `target_speed × min(alpha_factor, cte_factor)` — the worse of the two errors wins (not multiplied, which would double-penalize a rover only moderately off on both). **Validated** by replaying the actual bad run's logged trajectory through the new law: speed now drops to the `0.06` floor exactly during the worst of the divergence (`cte=-0.94m`), instead of staying at ~0.18-0.20 throughout as it did on the real run.

**Open, needs a decision:** the speed fix mitigates Bug 2's rate of growth but doesn't address the actuator-lag mismatch itself. A **steering-command slew-rate limiter** on the RPi side (cap how fast `steer_cmd` is allowed to change per tick, matched to what the actuator can plausibly track) would target the actual mechanism directly. Not built yet — additional scope beyond what was asked; worth deciding after seeing whether the speed fix alone is enough in the next field test.

**Not yet re-tested on hardware** — both fixes verified via smoke tests (including exact real-scenario replays) and by replaying the real bad run's trajectory through the new code, but no new AUTO field run has happened since.

**User-confirmed, open items (updated):**
- 1.6m effective lawnmower turn spacing (vs. the nominal 1.0m row spacing) — **accepted**, not a blocker.
- `MAX_STEER_ANGLE_DEG=45°` — still the STM32's reference/design value, no protractor-verified true mechanical limit supplied yet (the steering pot replacement/recalibration that was pending is done — see §3.9's history — but that gave raw-ADC calibration, not a measured lock angle).
- Cruise speed: resolved — **0.12 m/s** (§3.10), though see §3.11 below for a deeper calibration issue found since.

### 3.11 Actual-vs-Commanded Speed Mismatch (~2.8-3.2×) — Root Cause Found, Partial Fix Applied

Discussion of 5 further field logs (3 rough/diverging, including one manually-aborted runaway; 2 clean finishes) surfaced a bigger issue than tuning: **measured wheel speed (from encoder RPM) ran 2.8-3.2× the RPi's commanded speed, consistently, across every run** — worse at low commanded speed (3.18× at the 0.06 m/s floor) than at cruise (2.80× at 0.12 m/s).

**Root cause, confirmed with a field-measured data point:** `_ToThrottle()` in `ackermann.c` linearly maps `(0 RPM → THR_FWD_MIN_DAC)` to `(WHEEL_RPM_MAX=20 → DAC_MAX=4095)`. User measured (standing start, commanded RPM) that the wheels only overcome static friction at **3.5 RPM commanded** — which the *old* `THR_FWD_MIN_DAC=1100` formula maps to DAC≈1624, not 1100. Every commanded RPM between 0 and ~3.5 was landing in a dead zone (DAC 1100–1624) that looked like a valid slow-crawl command but produced zero real motion.

**Fix applied:** `THR_FWD_MIN_DAC` raised `1100 → 1624` in `ackermann_config.h` (full derivation in a comment there). **Source change only — not yet rebuilt or reflashed.**

**⚠️ Likely a partial fix, flagged explicitly:** the ratio only mildly improved with higher commanded speed (3.18× → 2.80× from 0.06→0.12 m/s) rather than dropping toward 1.0× — if this were purely a dead-zone issue, it should shrink much faster once comfortably past the breakaway point. A roughly-constant ~2.8× component even well above the breakaway speed suggests the *slope* of the same linear map (not just its floor) may also be miscalibrated — e.g. `WHEEL_RPM_MAX=20` might not be the true achievable max wheel RPM. User has offered to re-test after this change; comparing the re-test's ratio-vs-speed curve against this session's will show whether the floor fix alone closes the gap.

**Superseded — see §3.12.** The re-test showed the floor-raise made things *worse*, and a full empirical analysis found the real problem was the map's slope, not its floor. Rather than curve-fit a second open-loop map, the whole open-loop approach was replaced with closed-loop control for forward driving.

### 3.12 Open-Loop Throttle Mapping Replaced With Closed-Loop PI (Forward Only)

The §3.11 floor-raise (`THR_FWD_MIN_DAC` 1100→1624) was field-retested and made the actual/commanded speed ratio *worse* (3.4–5.5× vs the original 2.8–3.2×) — raising the floor while holding the far endpoint (`WHEEL_RPM_MAX→DAC_MAX`) fixed lifts the *entire* line, not just the low end, so every commanded RPM got over-mapped, not just near-zero ones. This was owned as a mistake mid-session (see scratchpad.md).

A follow-up empirical analysis (pooling real `(DAC, measured RPM)` pairs across all 7 field logs, 12,724 points, linear regression) showed the real relationship reaches `WHEEL_RPM_MAX` (20) at only DAC≈2171 (53% duty), not `DAC_MAX` — a genuine *slope* error, and the curve isn't perfectly linear either. A two-point re-fit was drafted but not applied.

**User's counter-proposal, adopted instead:** stop trying to curve-fit a static open-loop DAC map at all. Command wheel RPM directly and let a closed-loop PI (fed by the same encoder RPM already read every tick) compute the DAC, exactly like the BBB-era rover already did successfully on this same drivetrain (`Old_files/dev_bak/ugv_pid_waypoint.py`'s `BBBHardware`, `Kp=50, Ki=15`). This also naturally compensates for terrain/incline/traction changes in the field, which a static curve fundamentally cannot — directly answering the user's field observation about uneven paths and low-traction sections.

**Scope: forward driving only, explicit user decision** ("forward only"). Reverse driving is untouched — still the original open-loop `_ToThrottle()` with `THR_REV_MIN_DAC`/`THR_REV_MAX_DAC`.

**Implementation:**
- New `wheel_pid.c/h` — a `WheelPID_t` per wheel (`kp`, `ki`, `integral`), structurally identical to `steer_pid.h`'s `Init`/`Reset`/`Update` shape. `WheelPID_Update()` takes `(target_rpm, measured_rpm, dt_s)`, returns a DAC value: `error*kp + integral*ki` is clamped to `[WHEEL_PID_MIN_CORRECTION, DAC_MAX-THR_FWD_MIN_DAC]` and added on top of `THR_FWD_MIN_DAC` (now just a reasonable starting floor, not precision-critical — the integral term corrects away from it), then the final DAC is clamped to `[0, DAC_MAX]`. Gains `KP_WHEEL=50.0`, `KI_WHEEL=15.0` carried directly from the BBB code (same motors/gearbox/DAC hardware).
- `ackermann.c`: `_ToThrottle()` re-scoped to reverse-only (forward branch left as commented dead code, for reference). New `_ToThrottleClosedLoop(pid, target_rpm, measured_rpm, dt_s)` wraps `WheelPID_Update()` (returns 0 and resets the PID if target is ~0, to avoid integral windup while stopped). New `_BrakeThrottle(pid_L, pid_R)` resets both PIDs — called from every branch that used to zero the DAC directly without going through the throttle mapping (pivot-not-yet-locked, neutral-sticks-brake, `Ackermann_RunAuto`'s speed-deadband branch), so a stale integral term from the previous driving segment can't kick the wheels when driving resumes.
- `Ackermann_Run()` and `Ackermann_RunAuto()` both gained `meas_rpm_L, meas_rpm_R, dt_s, WheelPID_t *pid_L, WheelPID_t *pid_R` parameters. Every FORWARD throttle computation (pivot drive, normal forward driving, `RunAuto`'s forward branch) now calls `_ToThrottleClosedLoop()`; every REVERSE throttle computation is unchanged (`_ToThrottle(rpm, 1U)`).
- `main.c`: added static `wheel_pid_L`/`wheel_pid_R`, initialized alongside `steer_pid` in `USER CODE BEGIN 2`, fed `Encoder_GetRPM_L()/R()` and the loop's `dt_s` at both `Ackermann_Run`/`Ackermann_RunAuto` call sites. Also reset both PIDs in the disarmed/no-signal branch and the AUTO-selected-but-link-down branch (belt-and-suspenders — those paths bypass `ackermann.c` entirely and set `ack` fields directly).

**Not yet rebuilt, reflashed, or retested on hardware.** Source change only, in `Rover_closed_loop/`.

**Follow-up: `WHEEL_RPM_MAX` raised 20→25.** User field-measured the wheels actually reach 25 RPM, above the 20 RPM ceiling the firmware had been using (`WHEEL_RPM_MAX = MOTOR_RPM_MAX/GEAR_RATIO`, `400/20`). `MOTOR_RPM_MAX` raised `400→500` in `config.h` (the datasheet figure vs. the real measured max — `GEAR_RATIO` is a fixed mechanical spec, untouched), so `WHEEL_RPM_MAX` derives to 25.0 everywhere it's used, including `Ackermann_ComputeRPM()`'s forward RPM ceiling. Not yet rebuilt/reflashed/retested.

### 3.13 First PID Field Test — Tracking Confirmed Good, Dead-Start Stall Found and Mitigated

First real field test of §3.12/the `WHEEL_RPM_MAX` change: 2 straight-line runs. Once moving, tracking was excellent — cross-track error under 7cm and yaw drift under a couple degrees in both runs, confirming the Pure Pursuit + closed-loop PI combination works well together. Both runs ended early because the operator flipped SWB back to MANUAL (not a crash).

**Issue found:** run 1 sat completely still (0 RPM, 0 displacement) for **27.6 seconds** after the mission began commanding 0.12 m/s, before finally moving. Run 2 (~50 min later, identical firmware/gains) only stalled 2.95s.

**Root cause (worked out from PI math and timing — `dac_L/R` aren't in the telemetry log):** at 0.12 m/s target (~6.5 target RPM), `Kp=50 × 6.5 ≈ 325` correction (DAC≈1425, 35% duty) wasn't enough to break real-world static friction on run 1's ground. With the wheel not moving, error stays pinned at 6.5 every tick, so only the PI's integral term climbs — it took ~23s to hit `WHEEL_PID_MAX_INTEGRAL`'s clamp (150), pushing DAC to ≈3675 (90% duty), which finally broke it free a few seconds later. Run 2 needed far less (~1700 DAC, ~42% duty) — real terrain friction varies a lot run to run (plausibly run 1 loosened/rutted the same start patch), consistent with the traction variability flagged earlier in this session.

**Mitigation applied (RPi-side config only, user's chosen option):** doubled `CRUISE_SPEED_MPS` 0.12→0.24 and `MIN_SPEED_MPS` 0.06→0.12 in `rover_config.py`. **Not yet retested on hardware.**

**⚠️ Correction — the root-cause paragraph above is wrong.** The user identified the actual cause directly: SWB was simply still in MANUAL for that entire window — the mission script logs at 20Hz from launch regardless of switch position, so the CSV faithfully recorded the operator's own delay in flipping SWB to AUTO, not a stall. Checking the `auto_active` column (not done before writing the friction analysis) confirms this exactly: it reads 0 for the whole "stall," flips to 1, and `rpm_L/R` go nonzero **~150ms later** in both runs — a normal, fast PI response, not a 20+ second integral wind-up. `KP_WHEEL`/`WHEEL_PID_MAX_INTEGRAL` are not implicated by this data. The speed doubling above stands on its own (user's independent "feels slow" request) but its "shrinks the dead-start stall" justification does not hold and should be disregarded. Full trail: scratchpad.md, Mistake 16.

### 3.14 Intermittent One-Sided Straight-Line Bias — Traced to the Heading Lock

A further field log (`mission_20260911_173125`) prompted a full read-only re-analysis before any changes (user's explicit instruction). Found a real, well-evidenced pattern, distinct from anything above: `cte_m` never crosses zero across the entire ~186s/20m run (stays 0.000 to +0.069) and `steer_cmd_deg` is negative on literally every nonzero tick (3571/3571) — a fixed one-directional bias, not noise. Cross-checked against `mission_20260911_165910` (identical signature) and `_170745` (clean — steer splits ~50/50, cte crosses zero twice, same day, same firmware). **Intermittent**, and present in `165910` which predates this session's wheel-PID/speed work entirely — ruling those subsystems out.

**Root cause:** `Odometry`'s heading reference (the mission's "straight ahead," see §3.9) locked from a single IMU sample at mission start. `imu_calib_mag`/`imu_calib_sys` read 0 for the entire duration of every field log examined so far — the magnetometer never calibrates on this chassis (plausibly interference from the nearby drive motors/DAC — `imu.py`'s own `is_fully_calibrated()` already treats mag as unreliable). The BNO055's default NDOF fusion mode still blends that uncalibrated mag reading into `heading_deg` regardless. A single-instant lock against a magnetometer under active interference is a coin-flip: sometimes close to true heading (`170745`), sometimes several degrees off (`165910`, `173125`) — and since the reference intentionally never re-corrects mid-mission, a bad lock steers the *entire* run, with Pure Pursuit's proportional-only law settling into a steady one-sided correction rather than eliminating the error. This is orthogonal to speed (a fixed angular bias, not a responsiveness gap).

**Mitigation applied (user's chosen first step):** `Odometry.update()` now locks the reference from the circular mean (handles 0/360 wraparound) of `HEADING_LOCK_SAMPLES=30` (~1.5s @ 20Hz, new `rover_config.py` constant) consecutive readings instead of one. Pose is held at (0,0)/invalid during that window — the rover is expected to be stationary at script launch anyway, matching all 3 logs' actual behavior. `odometry.py`'s smoke test gained a Check 0 injecting ±5° jitter across the lock window, confirming the pose stays frozen/invalid throughout and the lock averages the jitter out rather than latching the last sample.

**Explicitly a partial mitigation.** A sustained interference bias present for the whole 1.5s window would average right through it. Next options if the bias recurs: switch the BNO055 to IMUPLUS mode (drops the magnetometer from fusion entirely — trades absolute-compass heading for gyro-integration drift immunity to motor interference), or physically relocate the IMU away from the motors/DAC/power wiring.

Also flagged (unrelated): `173125`'s `speed_cmd_ms` still maxed at 0.12 — the §3.13 `CRUISE_SPEED_MPS` doubling hadn't been synced to the RPi yet for this test.

**Not yet retested on hardware.** Pure-Python change (`odometry.py`, `rover_config.py`), no firmware involved.

### 3.15 Steering Pot L/R Center Mismatch — a Separate, Constant Bias

Discussing §3.14 further, `angle_L`/`angle_R` were checked specifically at commanded-straight (`steer_cmd_deg==0`, before any turn had been issued) — the one condition where true Ackermann geometry says both wheels should read the same angle (inner/outer divergence only applies mid-turn). They don't: a repeatable **~1.1-1.6° gap in 3 of 4 field logs, including the one run that tracked cleanly** — which rules this out as the explanation for §3.14's run-to-run variability (a constant hardware offset biases every run equally) but flags it as a real, separate issue worth fixing regardless, since `_MapToAngle()` in `ads1115.c` trusts each wheel's `ADC_*_CENTER_RAW` as exactly 0° with no runtime cross-check between the two. Most likely cause: the pot-replacement recalibration (§ADC_L/R_MIN/MAX/CENTER_RAW history, scratchpad.md) judged "straight" separately per wheel rather than against one shared physical reference for both at once.

**Tooling built:** `RPi_companion/calibrate_steering_pots.py` — walks full-left-lock / full-right-lock / center, printing live `angle_L`/`angle_R`/`delta` (non-blocking Enter-to-capture) so the operator can watch the two numbers agree before capturing the center point with a string-line across both wheels simultaneously. Doesn't need raw ADC in the UART frame (not present in `rpi_link.c`'s format) — instead exactly inverts `_MapToAngle()` using the current firmware constants to recover the true raw ADC at each captured position (round-trip verified < 1e-6 error over 1000 samples). Prints the 6 new `ADC_L/R_MIN/CENTER/MAX_RAW` values to paste into `ackermann_config.h`. Deployed to the RPi. **Two field runs done** (§3.16 below has the follow-up findings from those runs); new calibration values have not been committed to `ackermann_config.h` yet — the user chose to fix the actuator control first (§3.16) before locking in a recalibration, since the actuator's own approach-direction hysteresis was making "center" hard to measure repeatably in the first place.

### 3.16 Actuator Hysteresis Found, Then a Full Bang-Bang/PID Redesign

**Hysteresis discovered.** Two calibration runs of `calibrate_steering_pots.py` disagreed on where "center" was by **~2.9°** — close to the size of the thing being measured. Investigating why: settling to commanded-zero from full-left-lock vs. from full-right-lock left the wheels in measurably different physical positions — **+2.26° vs. -2.27° under the old calibration (a 4.53° gap)**, and re-mapping the same raw readings through the *new* calibration barely changed it (4.29°) — proving this is an independent actuator-control effect, not a sensor-calibration one. Root cause: `main.c`'s actuator control was pure bang-bang — 100% speed with no deceleration until the deadband check trips — so however much it overshoots past that trip point depends on approach direction and momentum, not a fixed physical point.

**Redesign, agreed over several rounds of discussion:**
- **Centering uses both pots individually; the differential keeps using the average.** `Ackermann_ComputeRPM()` is unchanged (still `steer.delta`, the user's explicit call — that's the standard bicycle-model convention and it's fine there). Only the actuator's own "am I centered" decision changes: when `|target_steer_deg| < CENTER_TARGET_EPS` (1.0°, i.e. returning to straight — the condition that actually drives the field drift), it now requires **both** `angle_L` and `angle_R` individually within `STEER_DEADBAND_DEG`, not just their average — directly closes the gap the user identified (two very different per-wheel readings can average to the same `delta`, hiding a real disagreement). Off-center targets keep the original delta-only check, since `angle_L != angle_R` is *expected* there (real Ackermann inner/outer divergence during a turn).
- **`steer_pid.c` activated** (dead code since the Phase 2 port — `SteerPID_Init()` was called at boot but `SteerPID_Update()` was never called). New two-zone control: bang-bang (100%) while `|error| > STEER_PROP_ZONE_DEG` (4°), PID takeover inside that zone — directly targets the overshoot that caused the hysteresis. `KP/KI/KD_STEER` (5.0/0.1/0.5, BBB-ported) are exercised on this hardware for the first time and flagged as unlikely to be well-tuned as-is.
- **`ACT_MIN_DUTY_PCT = 40.0f`** floors the PID's output (same role as `THR_FWD_MIN_DAC` for the rear wheels — a small computed duty can be too weak to break the actuator's static friction and stall short). Identified the actual hardware first via web search: almost certainly the **PA-12-300-1500** (300mm/7mm-s/12V — matches multiple Indian storefronts: Robu, Probots, Rees52, RoboticsDNA). Datasheets gave rated current (~3.8A loaded), full-load speed drop (7→5.5mm/s), a **10% duty-cycle rating**, and a self-locking screw — but no minimum-moving-duty spec (expected; same situation as the rear-motor stiction floor). 40% is a starting guess, not a measured value.
- **Watchdog against unsatisfiable centering.** The per-wheel check only has a solution if the real `angle_L`/`angle_R` mismatch is under `2 * STEER_DEADBAND_DEG` (3° now). If that mismatch ever grows (pot drift, a failing sensor), the PID could hunt indefinitely — and given the actuator's 10% duty-cycle rating just found, that's a real damage risk, not just an inconvenience. `STEER_CENTER_WATCHDOG_US` (2.5s) bounds the wait before falling back to the always-satisfiable delta-only check.
- **`STEER_DEADBAND_DEG` narrowed 2.5° → 1.5°** — the old value was sized to tolerate bang-bang's overshoot; the PID's gentler approach makes a tighter tolerance worth trying. Flagged to widen back up if the actuator ever hunts/oscillates right at the new boundary.

**Not yet rebuilt, reflashed, or retested.** Source change only; user will build and report back.

### 3.17 First Flash — Actuator Wobble at Center, Traced to the Duty Floor

User flashed §3.16's redesign and reported: *"the linear actuator is wobbling at zero position."* Root cause: `ACT_MIN_DUTY_PCT=40%` floored *any* nonzero PID correction up to 40% duty — with `STEER_DEADBAND_DEG` narrowed to 1.5°, even a fractional-degree correction snapped up to 40% was enough to overshoot straight back out the other side of the deadband every time, triggering the same correction in reverse: a self-sustaining limit-cycle, not the gentle creep-to-stop the PID zone was built to provide. Same category of mistake as the original `THR_FWD_MIN_DAC=1624` guess earlier this session — an unverified starting number turning out too aggressive once actually field-tested.

**Fix:** lowered `ACT_MIN_DUTY_PCT` 40→15 in `ackermann_config.h`. Still not a measured value — if wobble persists at 15%, next suspect is `KP_STEER`/`KI_STEER`/`KD_STEER` (also untuned BBB-ported gains, exercised on this hardware for the first time by this same redesign). Flagged secondary contributor: the new per-wheel L/R centering check could also be flip-flopping given the pot recalibration (§3.15) is still pending. Full trail: scratchpad.md, Mistake 17. **Not yet retested.**

**Update — wobble persisted at 15%.** User proposed the opposite theory: 15% may be *below* this self-locking-screw actuator's real breakaway torque, so it chatters in place rather than cleanly moving, instead of overshooting. Raised `ACT_MIN_DUTY_PCT` to 70 as a direct test — the result discriminates between the two theories (settles = torque theory confirmed; worse/faster = overshoot theory confirmed, reverse direction needed instead). Full trail: scratchpad.md. **Not yet retested.**

**Update — 70% made it worse, not better.** Confirms the original overshoot theory decisively: any floor of meaningful size relative to the 1.5° deadband overshoots back out every correction, and a bigger floor makes it bigger/faster — ruling out insufficient breakaway torque. `ACT_MIN_DUTY_PCT` set to 0 — a true no-op on the floor-clamp, letting the PID's raw output drive the actuator directly. Known, explicitly-flagged trade-off: very close to target the PID's own small output could legitimately be below real static friction and stall short instead of wobbling — expected, bounded by the existing `STEER_CENTER_WATCHDOG_US` fallback, not a new bug. If a stall gap turns out to matter, the next lever is `KP_STEER` itself (untuned), not another floor value. Full trail: scratchpad.md. **Not yet retested.**

---

## 4. Version Control

**Remote:** `https://github.com/sachu018/Autonomous_Ackermann` (private). Local repo at the project root, initial commit made 2026-09-09 covering everything on disk at that point (STM32 firmware, RPi companion code, ESP32 sniffer, documentation, and the archived BBB-era `Old_files/`).

**Workflow going forward:** after each meaningful code or doc change, a commit is made with a message explaining what changed and why (not just what), then pushed to `origin/main` immediately — no separate "please push" step needed.

**What's excluded** (`.gitignore`): `Rover_closed_loop/Debug/` (STM32CubeIDE build output — regenerated by Build All, not source) and Python `__pycache__/`/`*.pyc`. Everything else, including `Old_files/`'s historical CSV logs, is tracked in full per an explicit decision to keep the complete history rather than trim it.

**Local tooling note:** `gh` (GitHub CLI) isn't part of the base OS image on this dev laptop and there's no passwordless `sudo` here — it was installed as a self-contained binary to `~/.local/bin/gh` (already on `PATH` via `.bashrc`) rather than via a package manager. `gh auth setup-git` was required once, after `gh auth login`, before plain `git push` would work — `gh` storing a token doesn't automatically wire itself into git's credential helper.

---

## 5. Work Breakdown Structure & Phase Status

### Phase 1: Architecture, Review & Planning — [COMPLETED]
- [x] Analyzed `STM_ackermann_backup` modules.
- [x] Verified and documented 7 corrections + 1 design improvement (Kinematic `tanf`, PID derivative-on-measurement, ADC debounce, compile headers, reverse scaling).
- [x] Initialized dedicated tracking in `architecture.md`, `scratchpad.md`, and `works.md`.

### Phase 2: Module Code Integration into `Rover_closed_loop/` — [COMPLETED]
- [x] Added `ackermann_config.h`, `ads1115.h/.c`, `actuator.h/.c`, `steer_pid.h/.c`, `ackermann.h/.c` into `Rover_closed_loop/Core/`.
- [x] Applied verified bug fixes (kinematic `tanf`, PID derivative-on-measurement, ADC debounce hold, reverse scaling, `#include "config.h"`).
- [x] Updated `Rover_closed_loop/Core/Src/main.c` control loop and telemetry.
- [x] Verified `Rover_closed_loop/STM32F411CEUX_FLASH.ld` linker script is clean for GCC 10.

### Phase 3: Building & Firmware Verification — [COMPLETED]
- [x] Clean and build `Rover_closed_loop` project in STM32CubeIDE (0 errors, 0 warnings) — fixed 4 constants dropped during the Phase 2 port (`ACK_STRAIGHT_DEG`, `STEER_INTEGRAL_MAX_PCT`, `KP/KI/KD_STEER`; see scratchpad.md).
- [x] Flashed firmware.

### Phase 4: Step-by-Step Hardware Bring-Up & Calibration
- [x] **Step 1:** ADC feedback verification — done off-board via standalone ESP32 + ADS1115 rig (gain/wiring matched to STM32 firmware); both channels confirmed monotonic and consistent in sign (see scratchpad.md).
- [x] **Step 2:** Potentiometer min/max/center calibration (`ADC_*_MIN/MAX/CENTER_RAW`) — re-applied after both pots were replaced (3rd calibration overall; see scratchpad.md for the full history): L 3096(min)/4426(center)/5793(max), R 2124(min)/3167(center)/4160(max). Spans well-balanced this time (~3-5% split each side) — no repeat of the earlier 3.1x L/R mismatch. **Not yet rebuilt/reflashed** — user to do in STM32CubeIDE. ⚠️ True mechanical lock angle still not verified against `MAX_STEER_ANGLE_DEG` (45°) with a protractor — that constant is unchanged, still the nominal design value, not a measured one.
- [ ] **Step 3:** Actuator polarity & deadband verification — in progress. Actuator confirmed hunting/oscillating at zero on hardware with ±1.3° deadband; widened to ±2.5° (see scratchpad.md). Steering angle calibration replaced twice: first a flat per-wheel zero trim (fixed the zero-offset but broke left pivot, see scratchpad.md Mistake 9), now a proper 3-point (min/center/max) piecewise-linear calibration per wheel — analytically verified (straight=0°/0°, both locks=±45°/±45°). Also found + fixed a persistent left-drift-on-straight bug caused by `ACK_STRAIGHT_DEG` (1.0°) being narrower than `STEER_DEADBAND_DEG` (2.5°), raised to 3.0° (Mistake 10). **None of the above re-tested on hardware after flashing yet.**
- [ ] **Step 4:** Steering PID tuning (`Kp`, `Ki`, `Kd`).
- [ ] **Step 5:** Rear differential test with wheels on blocks.
- [ ] **Step 6:** Ground testing in field conditions.

### Phase 5: Autonomous Integration via Raspberry Pi — [PLANNING]
- [x] Reviewed old BBB autonomous stack (`Old_files/UGV_closed/`) for reusable guidance/localization logic vs. hardware-access code that must be replaced.
- [x] Decided division of responsibility: RPi = guidance/sensing brain, STM32 = real-time actuation server (see §3).
- [x] Decided mode arbitration: SWB repurposed from reverse-speed-cap to MANUAL/AUTO select; UART-link-loss in AUTO mode → brake (see §3.3, §3.5).
- [x] Drafted UART command/feedback frame layout (see §3.4).
- [x] Configured USART2 (PA2/PA3) in `Rover.ioc` / CubeMX — Asynchronous, RX via DMA1_Stream5 + IDLE interrupt (mirrors the USART1/iBUS pattern), code generated and verified against the §10.3 checklist.
- [x] Implemented UART command/feedback framing on the STM32 side (`rpi_link.c/h`) + `AUTO_UART_TIMEOUT_US` failsafe + SWB mode-select wiring in `main.c`. See scratchpad.md for the implementation notes and one regeneration-related regression found and fixed along the way.
- [x] Firmware rebuilt and reflashed to the STM32 with these changes.
- [x] UART link tested end-to-end with a live RPi — see §3.8. 20.0 frames/s, zero checksum failures, correct status bits, confirmed via both `check_stm32_link.py` and `read_encoders.py`, cross-checked with an independent ESP32 sniffer during bring-up.
- [x] IMU hardware-verified — `test_imu.py` shows live, sane heading/roll/pitch/calibration data from the DFRobot Fermion BNO055 on the RPi's I2C1 (see §3.6). Calibration ritual (`calibrate_imu.py`) not yet run.
- [x] Interconnection ported into `Documentations/Rover_study.md` (new §14) as the settled reference version, once verified working — `architecture.md`/`scratchpad.md`/`works.md` remain the working/build-log docs.
- [x] Guidance stack built: `rover_config.py` (shared tunables, mirrors STM32 `ackermann_config.h`), `waypoints.py` (straight/rectangle/circle/lawnmower pattern generation + CSV I/O), `odometry.py` (encoder+IMU dead-reckoning pose), `guidance.py` (Pure Pursuit). All three logic modules verified via standalone smoke tests (no hardware) — not yet deployed/run on the RPi itself (network connectivity to the Pi was down at write time) and not yet wired into a `mission.py` top-level loop that actually calls `uart_link.send_command()`. See §3.9 for the full design discussion and one real physical-feasibility finding (lawnmower turn radius).
- [ ] Wire RTK GNSS to the RPi (replacing the old BBB↔RPi TCP link for RTK). **Not started.**
- [ ] Bench test: RPi sends a *non-neutral* steer/speed target over UART with SWB physically flipped to AUTO on the transmitter, verify the STM32 actually drives the actuator/motors accordingly (only neutral 0°/0 m/s commands and passive listening have been tested so far — the AUTO-mode motion path itself is unexercised).
- [ ] Field test: full autonomous waypoint run.

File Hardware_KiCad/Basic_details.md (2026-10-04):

# Rover System — Complete Technical Reference

> **Author:** Auto-generated from BBB-backup-2026-07-01  
> **Purpose:** Give a new project engineer complete understanding of the rover system — hardware, software, Linux integration, and safety — so they can modify, extend, or debug it independently.

---

## Table of Contents

1. [System Overview](#1-system-overview)
2. [Hardware Architecture](#2-hardware-architecture)
3. [BeagleBone Black Pin Mapping](#3-beaglebone-black-pin-mapping)
4. [Linux Configuration](#4-linux-configuration)
5. [Software Architecture](#5-software-architecture)
6. [Control Pipeline — End to End](#6-control-pipeline--end-to-end)
7. [Startup Sequence](#7-startup-sequence)
8. [Safety Systems](#8-safety-systems)
9. [Known Hardware Details & Unknowns](#9-known-hardware-details--unknowns)
10. [How to Add a New Feature](#10-how-to-add-a-new-feature)
11. [Troubleshooting Guide](#11-troubleshooting-guide)
12. [File Reference](#12-file-reference)

---

## 1. System Overview

### What is this?

An **agricultural autonomous rover** with differential drive (two rear BLDC motors, two front castor wheels). Currently controlled manually via a **FlySky FS-i6X RC transmitter**. The goal is to eventually extend to full autonomous waypoint following.

### Controller

- **Board:** BeagleBone Black (BBB) — AM335x 1GHz ARM Cortex-A8
- **OS:** Debian Bookworm, kernel `5.10.168-ti-r83`
- **Python:** 3.11.2 (virtual environment at `/home/debian/Robot/env/`)

### Block Diagram

```
┌─────────────────────────────────────────────────────────────────────┐
│                         FlySky FS-i6X Transmitter                    │
│                   (CH1=Steering, CH2=Throttle,                      │
│                    CH5=SWC Speed, CH6=SWD Arm, CH7=SWB Rev Limit)   │
└─────────────────────────┬───────────────────────────────────────────┘
                          │ 2.4GHz RC link
                          ▼
┌─────────────────────────────────────────────────────────────────────┐
│                    FlySky FS-iA6B Receiver (iBUS)                    │
│                         UART output (115200 baud)                    │
└─────────────────────────┬───────────────────────────────────────────┘
                          │ UART5 — P8_37(TX), P8_38(RX) — /dev/ttyS5
                          ▼
┌─────────────────────────────────────────────────────────────────────┐
│                    BeagleBone Black (Linux Debian)                    │
│                                                                      │
│  main.py ─── 20Hz control loop                                       │
│    ├── flysky_receiver.py ── reads iBUS frames from UART5            │
│    ├── pipeline.py ────────── steering + kinematics                  │
│    ├── motor_controller.py ── writes DACs + GPIOs                    │
│    ├── motor_controller_closed_loop.py ── optional PID speed control │
│    └── kinematics.py ─────── diff-drive math (V, W → RPM_L, RPM_R)  │
│                                                                      │
│  GPIO outputs:                                                       │
│    P8_14 ── Contactor relay (main power to motor controllers)        │
│    P8_7  ── REV_LEFT (reverse direction select)                     │
│    P8_9  ── REV_RIGHT                                                │
│    P8_8  ── BRAKE_LEFT (brake input)                                │
│    P8_10 ── BRAKE_RIGHT                                              │
│                                                                      │
│  I2C Bus 2 (P9_19=SCL, P9_20=SDA):                                  │
│    addr 0x60 ── DAC R (right motor throttle voltage 0-5V)           │
│    addr 0x61 ── DAC L (left motor throttle voltage 0-5V)            │
│    addr 0x28 ── BNO055 IMU (9-axis absolute orientation)            │
│                                                                      │
│  eQEP (encoder counters via sysfs):                                  │
│    counter1 ── eQEP1, P8_35(CLK)/P8_33(STR), Left motor             │
│    counter2 ── eQEP2b, P8_12(CLK)/P8_11(STR), Right motor           │
└─────┬─────────────────────┬─────────────────────────────────────────┘
      │ DAC outputs (I2C)   │ GPIO outputs
      ▼                     ▼
┌──────────────────┐  ┌──────────────────────────────────────────────┐
│  MCP4725 DAC L    │  │  Optocoupler + Level Shifter Board           │
│  (addr 0x61)      │  │                                              │
│  0-5V analog out  │  │  GPIO → optocoupler → controller BRAKE input │
└────────┬──────────┘  │  GPIO → optocoupler → controller REV input   │
         │             └──────────────────┬───────────────────────────┘
         ▼                                ▼
┌─────────────────────────────────────────────────────────────────────┐
│                     BLDC Motor Controller (E-Scooter type)           │
│                                                                      │
│  LEFT controller:                                                    │
│    Throttle in: 0-5V (from DAC L via level shifter)                 │
│    Brake in:    GND when active (from optocoupler)                   │
│    Reverse in:  GND when active (from optocoupler)                   │
│    Motor out:   3-phase BLDC to LEFT wheel                           │
│                                                                      │
│  RIGHT controller:                                                   │
│    Throttle in: 0-5V (from DAC R via level shifter)                 │
│    Brake in:    GND when active (from optocoupler)                   │
│    Reverse in:  GND when active (from optocoupler)                   │
│    Motor out:   3-phase BLDC to RIGHT wheel                          │
└──────────────────────┬──────────────────────────────────────────────┘
                       ▼
┌─────────────────────────────────────────────────────────────────────┐
│  Mechanical:                                                        │
│    Rear: 2× BLDC motors (400 RPM max) → 1:20 gearbox → wheels      │
│    Front: 2× castor wheels (free-rotating)                          │
│    Wheel radius: 0.175 m                                            │
│    Track width:  0.6 m                                              │
│    Max wheel RPM: 20 (after gearbox)                                │
│    Max linear velocity: 0.366 m/s                                   │
│    Encoders: YT06-OP-600B (600 PPR, quadrature = 2400 cnt/rev)     │
└─────────────────────────────────────────────────────────────────────┘
```

---

## 2. Hardware Architecture

### 2.1 Drive System

| Parameter | Value | Source |
|---|---|---|
| Wheel radius (`R`) | 0.175 m | `config.py:4` |
| Track width (`L`) | 0.6 m | `config.py:5` |
| Max motor RPM | 400 | `config.py:9` |
| Gearbox ratio | 20:1 | `config.py:10` |
| Max wheel RPM | 20 | `config.py:12` (400/20) |
| Max linear velocity (`Vmax`) | 0.366 m/s | `config.py:6` |
| Max angular velocity (`Wmax`) | 1.22 rad/s | `config.py:7` |
| Spot turn RPM | 8.75 (wheel) | `config.py:28` |

### 2.2 Motor Controller Interface (E-Scooter BLDC Controllers)

Each motor controller has three control inputs:

| Input | Signal Type | Active State | Driven By |
|---|---|---|---|
| **Throttle** | Analog voltage | 0-5V (0=stop, 5V=max) | DAC (via level shifter) |
| **Brake** | Digital (GND pull) | Connect to GND = brake ON | GPIO → optocoupler (open drain) |
| **Reverse** | Digital (GND pull) | Connect to GND = reverse ON | GPIO → optocoupler (open drain) |

**Critical detail:** Both the brake and reverse inputs on the motor controller work by pulling the input pin to GND. The BeagleBone GPIOs drive optocouplers which sink the controller input to GND when active. This means:
- GPIO HIGH → optocoupler ON → controller input connected to GND → **active**
- GPIO LOW → optocoupler OFF → controller input floating → **inactive**

**Direction logic:** When reverse is OFF (floating), the motor runs forward with throttle. When reverse is ON (GND), the motor runs backward with throttle.

### 2.3 DAC System (Throttle Generation)

The BeagleBone generates the 0-5V analog throttle signals using **I2C DACs** (MCP4725 or compatible):

- **DAC L** (left motor): I2C address `0x61`
- **DAC R** (right motor): I2C address `0x60`
- Both on **I2C Bus 2** (P9_19 SCL, P9_20 SDA)
- 12-bit resolution: 0-4095 → 0-5V analog output
- Level shifter board between DAC output and motor controller input

**DAC write protocol** (from `motor_controller.py:57-64`):
```python
# 12-bit value split into two bytes
upper = (value >> 4) & 0xFF    # top 8 bits
lower = (value << 4) & 0xFF    # bottom 4 bits (shifted to nibble)
bus.write_i2c_block_data(addr, 0x40, [upper, lower])
```

The command byte `0x40` means "write DAC register, no EEPROM write" (standard MCP4725 fast write).

### 2.4 FlySky RC System

- **Transmitter:** FlySky FS-i6X (6+ channel)
- **Receiver:** FS-iA6B (iBUS protocol)
- **Connection:** UART5 at 115200 baud, `/dev/ttyS5`
- **Pins:** P8_37 (TX), P8_38 (RX)
- **Protocol:** iBUS — 32-byte frames at ~7ms intervals

**Channel mapping** (from `config.py:42-48`):

| Channel | Index | Control | Function |
|---|---|---|---|
| CH1 | 0 | `Xn` | Steering (Left/Right) |
| CH2 | 1 | `Yn` | Throttle (Forward/Reverse) |
| CH5 | 4 | `SWC` | 3-position switch → forward speed limit |
| CH6 | 5 | `SWD` | 2-position switch → arm/disarm contactor |
| CH7 | 6 | `SWB` | 2-position switch → reverse speed limit |

**Stick range:** 1000-1500-2000 (min-center-max)  
**Deadband:** 0.05 (±5% around center)  
**RC timeout:** 0.4 seconds — if no valid frame for 400ms, signal is considered lost

**Speed limit switch positions:**

| Switch | Position | Raw Value | Speed Limit |
|---|---|---|---|
| SWC (CH5) | Low | <1250 | 30% forward |
| SWC | Mid | 1250-1750 | 60% forward |
| SWC | High | >1750 | 100% forward |
| SWB (CH7) | Low | <1500 | 60% reverse |
| SWB | High | >1500 | 100% reverse |

### 2.5 Encoder System (eQEP)

- **Encoder model:** YT06-OP-600B (600 pulses per revolution)
- **Decoding:** Quadrature (4× edges per pulse) = 2400 counts/rev
- **Location:** Motor shaft (before gearbox)
- **Interface:** TI eQEP peripheral → Linux counter subsystem (sysfs)

| Motor | eQEP | Counter Device | Phase A | Phase B |
|---|---|---|---|---|
| Left | eQEP1 | `/sys/bus/counter/devices/counter1/count0/count` | P8_35 | P8_33 |
| Right | eQEP2b | `/sys/bus/counter/devices/counter2/count0/count` | P8_12 | P8_11 |

**RPM calculation** (from `main.py:95-119`):
```python
delta = curr - prev
# Handle 32-bit rollover
if delta > 2**31: delta -= 2**32
if delta < -2**31: delta += 2**32
rpm = (delta / (2400 * dt)) * 60.0    # motor shaft RPM (before gearbox)
```

### 2.6 IMU (BNO055)

- **Sensor:** Bosch BNO055 — 9-axis absolute orientation sensor
- **Interface:** I2C Bus 2 (shared with DACs)
- **Address:** 0x28 (standard)
- **Library:** Adafruit CircuitPython BNO055 driver
- **Features:** On-chip fusion → Euler angles, gravity-compensated accel
- **Calibration:** Saved to `/home/debian/Robot/bno055_calibration.json`

**Optional:** The system runs without IMU if the BNO055 is not connected — it degrades gracefully.

### 2.7 Power and Safety

- **Main contactor:** GPIO-controlled relay (P8_14, GPIO 26) that enables/disables power to the motor controllers
- **Contact state:** HIGH = engaged (motors can run), LOW = disengaged (motors physically disconnected from power)
- **Arming:** Only happens when SWD (CH6) on the transmitter is ON (>1450 raw) and debounced for 500ms
- **Signal loss:** If RC signal is lost for >400ms, motors stop immediately
- **Startup state:** Disarmed — must arm via SWD before any motion

---

## 3. BeagleBone Black Pin Mapping

### 3.1 GPIO Pins

| Function | P9/P8 Pin | GPIO # | Sysfs Export | Direction | Logic |
|---|---|---|---|---|---|
| CONTACTOR | P8_14 | 26 | `/sys/class/gpio/gpio26` | OUT | HIGH=engaged, LOW=disengaged |
| REV_LEFT | P8_7 | 66 | `/sys/class/gpio/gpio66` | OUT | HIGH=reverse ON, LOW=forward |
| BRAKE_LEFT | P8_8 | 67 | `/sys/class/gpio/gpio67` | OUT | HIGH=brake ON, LOW=released |
| REV_RIGHT | P8_9 | 69 | `/sys/class/gpio/gpio69` | OUT | HIGH=reverse ON, LOW=forward |
| BRAKE_RIGHT | P8_10 | 68 | `/sys/class/gpio/gpio68` | OUT | HIGH=brake ON, LOW=released |

**Important:** These GPIOs drive optocouplers. When the GPIO goes HIGH, the optocoupler turns ON, which connects the motor controller's BRAKE or REV input to GND (activating that function).

### 3.2 I2C Pins

| Bus | Pin | Function | Devices |
|-----|-----|---|---|
| I2C2 | P9_19 | SCL (clock) | DAC L (0x61), DAC R (0x60), BNO055 (0x28) |
| I2C2 | P9_20 | SDA (data) | Same as above |

Bus number: **2** (opened as `smbus2.SMBus(2)` in `motor_controller.py:32`)

### 3.3 UART Pins

| UART | Pin | Function | Device |
|---|-----|---|---|
| UART5 | P8_37 | TX (from BBB) | FlySky FS-iA6B receiver |
| UART5 | P8_38 | RX (to BBB) | FlySky FS-iA6B receiver |

Device node: `/dev/ttyS5`, 115200 baud, 8N1

### 3.4 eQEP (Encoder) Pins

| eQEP | Counter | Pin A (CLK) | Pin B (STR) | Motor |
|---|---|---|---|---|
| eQEP1 | counter1 | P8_35 | P8_33 | Left |
| eQEP2b | counter2 | P8_12 | P8_11 | Right |

### 3.5 Pinmux Configuration (from `startup.sh`)

```bash
# Applied at boot by uEnv.txt overlays (no manual config-pin needed):
#   UART5  (P8_37/P8_38)
#   eQEP1  (P8_35/P8_33)
#   eQEP2b (P8_12/P8_11)

# Applied by startup.sh via config-pin:
config-pin P8_7  gpio    # REV_LEFT
config-pin P8_8  gpio    # BRAKE_LEFT
config-pin P8_9  gpio    # REV_RIGHT
config-pin P8_10 gpio    # BRAKE_RIGHT
config-pin P8_14 gpio    # CONTACTOR
config-pin P9_19 i2c     # I2C2_SCL
config-pin P9_20 i2c     # I2C2_SDA
```

---

## 4. Linux Configuration

### 4.1 Boot Configuration (`/boot/uEnv.txt`)

```bash
uname_r=5.10.168-ti-r83          # Kernel version
enable_uboot_overlays=1           # Enable U-Boot overlay loading
uboot_overlay_addr4=/lib/firmware/BB-UART5-00A0.dtbo
uboot_overlay_addr5=/lib/firmware/bone_eqep1-00A0.dtbo
uboot_overlay_addr6=/lib/firmware/bone_eqep2b-00A0.dtbo
disable_uboot_overlay_video=1     # HDMI disabled (saves pins)
disable_uboot_overlay_audio=1     # Audio disabled
uboot_overlay_pru=AM335X-PRU-UIO-00A0.dtbo   # PRU in UIO mode
enable_uboot_cape_universal=1     # Universal cape support
```

### 4.2 File System (`/etc/fstab`)

```
/dev/mmcblk0p3  /          ext4  noatime,errors=remount-ro  0  1
/dev/mmcblk0p1  /boot/firmware  vfat  user,uid=1000,gid=1000  0  2
/dev/mmcblk0p2  none       swap  sw                           0  0
debugfs         /sys/kernel/debug  debugfs  defaults          0  0
```

### 4.3 Kernel Modules (`/etc/modules`)

Empty — no additional modules loaded at boot. eQEP/UART/I2C support is built into the kernel or loaded via DT overlays.

### 4.4 Service: `robot.service`

```ini
[Unit]
Description=Robot Motor Controller
After=network.target

[Service]
Type=simple
User=debian
WorkingDirectory=/home/debian/Robot
ExecStart=/bin/bash /home/debian/Robot/startup.sh
Restart=on-failure
RestartSec=5
StartLimitIntervalSec=60
StartLimitBurst=3

[Install]
WantedBy=multi-user.target
```

- **What it does:** Starts `startup.sh` as user `debian` on boot
- **Restart policy:** Restarts on failure (max 3 times in 60 seconds, 5s between attempts)
- **Symlink:** Also present as `Robot.service` and `rover.service` (older copies)

---

## 5. Software Architecture

### 5.1 Module Dependency Graph

```
main.py (entry point, 20Hz control loop)
├── config.py                   (all constants, pin numbers, addresses)
├── pipeline.py                 (control logic: steering → RPM)
│   └── utils/kinematics.py     (differential drive math)
├── drivers/flysky_receiver.py  (iBUS protocol over UART)
├── drivers/motor_controller.py (DAC + GPIO low-level control)
└── drivers/motor_controller_closed_loop.py  (optional PID wrapper)
```

### 5.2 Supporting Files

| File | Purpose |
|---|---|
| `interactive_sim.py` | Hardware-free simulation of `pipeline.py` — test steering logic |
| `teleop_key.py` | Keyboard teleoperation over SSH (for testing without RC) |
| `visualize_imu.py` | Web dashboard — 3D chassis view + real-time charts (SSE) |
| `dashboard.py` | Older version of web dashboard |
| `encoder_monitor.py` | Standalone RPM monitor from eQEP counters |
| `monitor_raw_counts.py` | Debug script — raw eQEP count polling |
| `test_pins.py` | Hardware test — sets GPIOs HIGH for multimeter check |
| `diagnostic_wheels.py` | Direct motor test — writes DAC values without main loop |
| `ugv_logger.py` | CSV data logger for post-run analysis |
| `setup_service.py` | Installs `robot.service` into `/etc/systemd/system/` |
| `stop_service.py` | Stops the `robot.service` |

### 5.3 Data Flow (Execution Path)

```
FlySky Transmitter sticks
        │
        ▼ [2.4GHz RF]
FlySky FS-iA6B Receiver
        │
        ▼ [UART5, 115200 baud, iBUS protocol]
flysky_receiver.py:read()
  ├── _read_frame()       ← parse 32-byte iBUS frame, validate checksum
  ├── _to_float(raw)      ← convert 1000-2000 → -1.0 to +1.0 (with deadband)
  ├── _swc_to_speed()     ← 3-position → 0.30 / 0.60 / 1.00
  └── _swb_to_speed()     ← 2-position → 0.60 / 1.00
        │
        ▼ [returns: Xn, Yn, fwd_safe_pct, rev_safe_pct, swd_on, rc_ok]
main.py (20Hz loop)
  │
  ├── 1. Read receiver          → Xn, Yn, swd_on, rc_ok, etc.
  ├── 2. _handle_contactor()    → edge-detect + debounce on swd_on
  │     └── motors.energize_system() / deenergize_system()
  ├── 3. Check motors_permitted = motors.armed AND rc_ok
  │
  ├── 4. IF permitted:
  │     └── run_pipeline(Xn, Yn, fwd_safe_pct, rev_safe_pct)
  │           ├── Check BRAKE condition (neutral sticks or no RC)
  │           ├── Check SPOT TURN (Yn=0, Xn≠0)
  │           │     └── return SPOT_RPM to one wheel, 0 to other
  │           ├── Differential drive:
  │           │     ├── V = Yn * Vmax                     ← linear velocity
  │           │     ├── W_scale = (|Xn|³)/(|Yn|+ε) * ε   ← speed-scaled steering
  │           │     ├── W = copysign(W_scale, Xn) * Wmax  ← angular velocity
  │           │     ├── _apply_safety(V, W, safe_pct)     ← speed limit
  │           │     └── compute_rpm(V, W, WHEEL_RPM_MAX)  ← kinematics
  │           └── _to_throttle(rpm)                       ← RPM → DAC value
  │                 └── int((abs(rpm) / WHEEL_RPM_MAX) * 4095)
  │     ↓ returns: state, V, W, rpm_L, rpm_R, thr_L, thr_R
  │
  ├── 5. Drive motors:
  │     ├── BRAKE        → motors.brake()       (DAC=0, brake GPIO=HIGH)
  │     ├── DISARMED/NO SIGNAL → motors.stop()  (DAC=0, all GPIO=LOW)
  │     ├── REV states   → brake_then_reverse() (brake 100ms, then reverse)
  │     └── FWD states   → set_motors()         (DAC + GPIO)
  │           ├── Direction change? → DAC=0 → toggle REV GPIOs → wait 80ms
  │           └── set REV GPIOs, release BRAKE GPIOs, write DAC values
  │
  ├── 6. _update_encoders()    ← read eQEP counters, compute RPM
  ├── 7. _send_telemetry()     ← UDP packet to localhost:5005 (for web UI)
  └── 8. Rate-limit to 20Hz   ← time.sleep(DT - elapsed)
```

### 5.4 Threading Model

- **Single-threaded** — the main loop in `main.py` runs sequentially
- **Exception:** `visualize_imu.py` runs as a **separate process** (launched from `startup.sh:78`), which starts its own threads:
  - Thread 1: UDP listener for telemetry + BNO055 polling
  - Thread 2: HTTP server (SSE + REST) for the web dashboard
- The main control loop is NOT multithreaded — no thread safety concerns in the critical path

---

## 6. Control Pipeline — End to End

```
FlySky Stick Position
   CH1 = 0.3 (right), CH2 = 0.5 (half forward)
        │
        ▼
[1] flysky_receiver.py:read()
    → Xn = +0.30, Yn = +0.50
    → fwd_safe_pct = 0.60 (SWC in mid position)
    → rev_safe_pct = 1.00 (SWB in high position)
    → swd_on = True, rc_ok = True
        │
        ▼
[2] main.py:_handle_contactor(True)
    → Rising edge detected, debounce OK
    → motors.energize_system()
    → GPIO P8_14 = HIGH (contactor closes, power to motor controllers)
        │
        ▼
[3] run_pipeline(Xn=0.30, Yn=0.50, fwd=0.60, rev=1.00, rc_ok=True)
    │
    ├─ Not BRAKE (sticks not neutral)
    ├─ Not SPOT (Yn ≠ 0)
    ├─ going_fwd = True (Yn > 0)
    ├─ safe_pct = 0.60
    │
    ├─ V = 0.50 × 0.366 m/s = 0.183 m/s
    │
    ├─ W_scale = (0.30³) / (0.50 + 0.30) × 0.30
    │         = 0.027 / 0.80 × 0.30
    │         = 0.0101
    ├─ W = +0.0101 × 1.22 = +0.0124 rad/s
    │
    ├─ _apply_safety(V=0.183, W=0.0124, safe=0.60)
    │   v_limit = 0.366 × 0.60 = 0.2196
    │   V = min(0.183, 0.2196) = 0.183 (unchanged)
    │
    ├─ compute_rpm(V=0.183, W=0.0124, limit=20.0)
    │   ├─ VL = 0.183 - (0.6/2) × 0.0124 = 0.183 - 0.0037 = 0.1793
    │   ├─ VR = 0.183 + 0.0037 = 0.1867
    │   ├─ rpm_L = (0.1793 / (2π × 0.175)) × 60 = 9.79
    │   ├─ rpm_R = (0.1867 / (2π × 0.175)) × 60 = 10.20
    │   ├─ peak = 10.20 < 20.0 (no scaling needed)
    │   ├─ MIN_RATIO check: faster=10.20, slower_min=2.04
    │   │   rpm_L=9.79 > 2.04 ✓, rpm_R=10.20 > 2.04 ✓
    │   └─ return rpm_L=9.79, rpm_R=10.20
    │
    ├─ _to_throttle(9.79)  → int((9.79/20.0) × 4095) = int(2004) = 2004
    ├─ _to_throttle(10.20) → int((10.20/20.0) × 4095) = int(2088) = 2088
    │
    └─ return "FWD RIGHT", V=0.183, W=0.0124, rpm_L=9.79, rpm_R=10.20,
             thr_L=2004, thr_R=2088
        │
        ▼
[4] motors.set_motors(rpm_L=9.79, rpm_R=10.20, dac_L=2004, dac_R=2088)
    │
    ├─ rpm_L_mod = 9.79 × 1 = 9.79 (LEFT_MOTOR_DIR = 1)
    ├─ rpm_R_mod = 10.20 × 1 = 10.20
    ├─ new_dir_L = rpm_L < 0 → False (forward)
    ├─ new_dir_R = rpm_R < 0 → False (forward)
    ├─ dir_changed = (False != last_dir_L) or (False != last_dir_R) = False
    │
    ├─ REV_LEFT GPIO = LOW, REV_RIGHT GPIO = LOW  (forward direction)
    ├─ BRAKE_LEFT GPIO = LOW, BRAKE_RIGHT GPIO = LOW (brakes off)
    ├─ wait 20ms (MOTOR_SEQ_DELAY)
    │
    ├─ I2C write to DAC L (0x61): value 2004
    │   → upper = (2004 >> 4) & 0xFF = 0x7D
    │   → lower = (2004 << 4) & 0xFF = 0x40
    │   → bus.write_i2c_block_data(0x61, 0x40, [0x7D, 0x40])
    │
    ├─ I2C write to DAC R (0x60): value 2088
    │   → upper = (2088 >> 4) & 0xFF = 0x82
    │   → lower = (2088 << 4) & 0xFF = 0x80
    │   → bus.write_i2c_block_data(0x60, 0x40, [0x82, 0x80])
    │
    ▼
[5] DAC outputs: L = ~2.45V, R = ~2.55V
    │
    ▼ [Level shifters]
[6] Motor controller throttle inputs: L = ~2.45V, R = ~2.55V
    │
    ▼ [BLDC controller interprets voltage as speed command]
[7] Left motor spins forward at ~49% speed
    Right motor spins forward at ~51% speed
    → Rover moves forward and slightly right (differential steering)
```

---

## 7. Startup Sequence

### Power-On to main.py

```
Step 1: Power applied
  └─ ROM bootloader loads from eMMC/SD card

Step 2: U-Boot (secondary bootloader)
  └─ Reads /boot/uEnv.txt
     ├─ Loads kernel: vmlinuz-5.10.168-ti-r83
     ├─ Loads Device Tree: am335x-boneblack-uboot-univ.dtb
     ├─ Applies overlays (uEnv.txt lines 19-21):
     │   ├─ BB-UART5-00A0.dtbo    → UART5 on P8_37/P8_38
     │   ├─ bone_eqep1-00A0.dtbo  → eQEP1 on P8_35/P8_33
     │   └─ bone_eqep2b-00A0.dtbo → eQEP2b on P8_12/P8_11
     ├─ Disables HDMI (saves pins)
     ├─ Disables audio
     └─ Boots kernel

Step 3: Kernel boots
  ├─ Mounts rootfs from /dev/mmcblk0p3 (ext4)
  ├─ Mounts /boot/firmware from /dev/mmcblk0p1 (vfat)
  ├─ Initializes hardware drivers:
  │   ├─ I2C2 (P9_19/P9_20) — built-in
  │   ├─ UART5 (P8_37/P8_38) — from overlay
  │   ├─ eQEP1, eQEP2 — from overlays
  │   └─ GPIO modules
  └─ Starts systemd (PID 1)

Step 4: systemd starts services
  ├─ Enables multi-user.target
  │   └─ robot.service is WantedBy=multi-user.target
  │
  └─ Executes robot.service:
      User=debian
      ExecStart=/bin/bash /home/debian/Robot/startup.sh

Step 5: startup.sh runs
  │
  ├─ export BLINKA_FORCEBOARD=BEAGLEBONE_BLACK
  │   (Tells Blinka library: "act like a BBB" — needed since EEPROM
  │    checks may fail in some cases)
  │
  ├─ config-pin P8_7  gpio     (REV_LEFT)
  ├─ config-pin P8_8  gpio     (BRAKE_LEFT)
  ├─ config-pin P8_9  gpio     (REV_RIGHT)
  ├─ config-pin P8_10 gpio     (BRAKE_RIGHT)
  ├─ config-pin P8_14 gpio     (CONTACTOR)
  ├─ config-pin P9_19 i2c      (I2C2_SCL)
  ├─ config-pin P9_20 i2c      (I2C2_SDA)
  │
  ├─ Export GPIOs to sysfs:
  │   echo 26 > /sys/class/gpio/export     (P8_14)
  │   echo 66 > /sys/class/gpio/export     (P8_7)
  │   echo 67 > /sys/class/gpio/export     (P8_8)
  │   echo 68 > /sys/class/gpio/export     (P8_10)
  │   echo 69 > /sys/class/gpio/export     (P8_9)
  │
  ├─ Enable eQEP counters:
  │   echo 4294967295 > counter1/count0/ceiling
  │   echo 4294967295 > counter2/count0/ceiling
  │   echo 1 > counter1/count0/enable
  │   echo 1 > counter2/count0/enable
  │
  ├─ Create log directory, prune old logs (keep 10)
  │
  ├─ Launch visualizer (background):
  │   python3 visualize_imu.py &
  │
  └─ Launch main.py (foreground, replaces bash via exec):
      exec python3 main.py

Step 6: main.py starts
  ├─ Creates FlySkyReceiver()    → opens /dev/ttyS5
  ├─ Creates MotorController()   → opens I2C bus 2, sets up GPIOs
  ├─ Initializes eQEP encoders
  ├─ Attempts BNO055 IMU init
  ├─ Sets up signal handlers (SIGINT, SIGTERM → safe shutdown)
  └─ Enters 20Hz control loop
```

---

## 8. Safety Systems

### 8.1 Physical Safety

| Safety Feature | Mechanism | File |
|---|---|---|
| Main contactor | Relay on P8_14 disconnects motor controller power | `motor_controller.py:42-55` |
| Contactor arming | Only via SWD switch — edge-detect + 500ms debounce | `main.py:277-296` |
| Disarmed by default | Contactor OFF at startup — must arm manually | `main.py:299-300` |

### 8.2 Software Safety

| Safety Feature | Mechanism | File |
|---|---|---|
| RC signal loss | 400ms timeout → forces BRAKE state | `flysky_receiver.py:87-89` |
| Both sticks neutral | Yn=0 AND Xn=0 → BRAKE state | `pipeline.py:18-19` |
| No RC → no motion | `motors_permitted = motors.armed AND rc_ok` | `main.py:312` |
| Speed limits (SWC/SWB) | Transmitter switches limit max speed | `flysky_receiver.py:67-74` |
| Shutdown signal handler | SIGINT/SIGTERM → brake + deenergize + close serial | `main.py:263-271` |
| Override via DISARMED | SWD off → contactor opens → motors stop | `main.py:291-294` |
| Reverse brake sequence | 100ms brake before engaging reverse | `motor_controller.py:128-143` |

### 8.3 Startup Safety

- The robot starts **DISARMED** — the contactor is open, no power to motor controllers
- The console prints: *"Arm the robot by flipping SWD (CH6) to ON"*
- If the transmitter is off or out of range, `rc_ok=False` and motors stay stopped
- The contactor debounce prevents accidental arming from switch bounce

---

## 9. Known Hardware Details & Unknowns

### 9.1 Verified from Code

| Item | Detail | Source |
|---|---|---|
| BBB model | BeagleBone Black (AM335x) | `config-5.10.168-ti-r83` has AM335x symbols |
| Kernel | 5.10.168-ti-r83 | `boot/uEnv.txt:3` |
| Python | 3.11.2 | `env/pyvenv.cfg` |
| DAC type | MCP4725 (12-bit, I2C) | Write protocol = MCP4725 fast write, `auto_calibrate_bno055.py` imports `adafruit_mcp4725` |
| DAC addresses | L=0x61, R=0x60 | `config.py:54-55` |
| I2C bus | Bus 2 | `motor_controller.py:32` |
| IMU | BNO055 | `main.py:150-158`, `auto_calibrate_bno055.py` |
| Encoder | YT06-OP-600B, 600 PPR | `main.py:65`, `encoder_monitor.py:27` |
| eQEP pinout | Left=P8_35/33, Right=P8_12/11 | `encoder_monitor.py:33-40`, `startup.sh` overlays |
| UART5 pins | P8_37/38 | `startup.sh` overlay reference |
| GPIO pins | P8_14=26, P8_7=66, P8_8=67, P8_9=69, P8_10=68 | `startup.sh:42` |
| Wheel radius | 0.175 m | `config.py:4` |
| Track width | 0.6 m | `config.py:5` |
| Gear ratio | 20:1 | `config.py:10` |
| Motor max RPM | 400 | `config.py:9` |
| FlySky protocol | iBUS | `flysky_receiver.py` |

### 9.2 Likely (Strong Evidence)

| Item | Detail | Reasoning |
|---|---|---|
| DAC model | MCP4725 | Write protocol matches, `auto_calibrate_bno055.py` explicitly imports `adafruit_mcp4725` |
| Contactor type | Mechanical relay, NO (normally open) | GPIO HIGH = engaged, LOW = disengaged |
| Optocoupler type | Digital isolator (e.g., PC817) | Standard practice for GPIO-to-controller isolation |
| Level shifter | Analog op-amp or voltage divider | DAC output (0-5V) needs buffering for motor controller input |
| Encoder mounting | Motor shaft (pre-gearbox) | `main.py:65` comment and RPM calc uses counts/rev without gear ratio |

### 9.3 Unknown (Not Determined From Code)

| Item | Notes |
|---|---|
| BLDC controller brand/model | "E-scooter controller" — exact specs unknown |
| Optocoupler circuit schematic | Exact resistor values, wiring unknown |
| Level shifter circuit | Gain, offset, power supply unknown |
| Contactor coil voltage | 5V? 12V? Driven by GPIO + transistor? |
| BNO055 I2C address | 0x28 is standard, not explicitly set in code |
| Power supply voltages | Battery voltage, regulator outputs unknown |
| Motor controller min throttle | At what DAC value does the motor start moving? |
| Encoder wiring | Pull-up resistors? Differential or single-ended? |
| FlySky receiver wiring | Direct UART or inverter needed? (iBUS needs inverted signal) |
| Current rating of system | Fuse values, cable gauge unknown |
| Safety circuit (E-stop) | Hardware E-stop or only software? |

---

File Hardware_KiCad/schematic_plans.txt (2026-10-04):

===============================================================================
ROVER SYSTEM - SCHEMATIC INTEGRATION PLAN: ENCODERS (YT06-OP-1M)
===============================================================================
Project: Rover KiCad Design (/home/robin/Documents/Kicad/Rover)
Schematic: kicad_setup.kicad_sch
Target Components: YT06-OP-1M Optical Quadrature Encoders (Left & Right Wheels)

1. SYSTEM & HARDWARE OVERVIEW
-------------------------------------------------------------------------------
The rover uses differential drive with two BLDC motors. Encoder feedback is processed
by the hardware eQEP (Enhanced Quadrature Encoder Pulse) peripherals on the BeagleBone Black.

  - Left Wheel Encoder:  YT06-OP-1M (ENC1) -> eQEP1 (P8_35 / P8_33)
  - Right Wheel Encoder: YT06-OP-1M (ENC2) -> eQEP2b (P8_12 / P8_11)
  - Power Supply: Regulated 5V DC from Step-Down Converter U6 (Pin 3 VOUT+, Pin 4 VOUT-)
  - Signal Filtering: 104 (100nF) ceramic capacitors on each phase line to GND

2. EXACT PINOUT & CONNECTION MAPPING
-------------------------------------------------------------------------------
A. Left Wheel Encoder (ENC1 - YT06-OP-1M):
   Location: Placed at (X: 45.72mm, Y: 165.10mm) on schematic canvas (Left side of BBB M1)
   - Pin 3 (Phase A Output) -> Wired to BBB Pin P8_35 (Canvas: 81.28mm, 166.37mm)
   - Pin 4 (Phase B Output) -> Wired to BBB Pin P8_33 (Canvas: 81.28mm, 163.83mm)
   - Pin 1 (VCC)            -> Connected to +5V power net (from U6 VOUT+)
   - Pin 2 (GND)            -> Connected to power:GND symbol

B. Right Wheel Encoder (ENC2 - YT06-OP-1M):
   Location: Placed at (X: 193.04mm, Y: 101.60mm, Mirrored X) (Right side of BBB M1)
   - Pin 3 (Phase A Output) -> Wired to BBB Pin P8_12 (Canvas: 152.40mm, 102.87mm)
   - Pin 4 (Phase B Output) -> Wired to BBB Pin P8_11 (Canvas: 152.40mm, 100.33mm)
   - Pin 1 (VCC)            -> Connected to +5V power net (from U6 VOUT+)
   - Pin 2 (GND)            -> Connected to power:GND symbol

3. FILTERING CAPACITORS (104 / 100nF)
-------------------------------------------------------------------------------
Placed directly on signal lines adjacent to the BeagleBone Black eQEP input pins:
   - C5 (104 / 100nF): Connected between Left Phase A (P8_35) and GND
   - C6 (104 / 100nF): Connected between Left Phase B (P8_33) and GND
   - C7 (104 / 100nF): Connected between Right Phase A (P8_12) and GND
   - C8 (104 / 100nF): Connected between Right Phase B (P8_11) and GND

4. POWER SUPPLY REGULATION INTEGRATION
-------------------------------------------------------------------------------
   - Step-Down Converter U6 (HiLink 48V/8V to 5V Module):
     * Pin 3 (VOUT+ @ 58.42mm, 77.47mm) -> Net label +5V supplying ENC1 VCC & ENC2 VCC
     * Pin 4 (VOUT- @ 58.42mm, 80.01mm) -> Net label GND connected to system GND
===============================================================================

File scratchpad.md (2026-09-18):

# Scratchpad — Mistakes, Root Causes, and Corrections

This document tracks mistakes encountered during the project evolution, how they were diagnosed, and how they were corrected.

---

### Mistake 1: Missing `config.h` Include in `steer_pid.c`
- **What happened:** `SteerPID_Update()` in `steer_pid.c` used `LOOP_HZ` for fallback $dt$ calculation, but never included `config.h`.
- **How it was found:** Code audit of `#include` dependencies.
- **How it was corrected:** Added `#include "config.h"` to `steer_pid.c`.

---

### Mistake 2: Kinematic Turning Radius Calculated with `sinf()` instead of `tanf()`
- **What happened:** `Ackermann_ComputeRPM()` used `R_c = ACK_WHEELBASE_M / sinf(delta_rad)` to calculate turning radius. In bicycle kinematics, turning radius about the rear axle center is $R_{\text{rear}} = \frac{W_b}{\tan(\delta)}$. Using $\sin(\delta)$ computed radius to the front axle ($R_{\text{front}} = \frac{W_b}{\sin(\delta)}$), causing a ~41% error at $45^\circ$ lock ($0.80\text{ m}$ true vs $1.13\text{ m}$ computed) and severe tire scrub.
- **How it was found:** Mathematical kinematic derivation from the Ackermann right triangle.
- **How it was corrected:** Replaced `sinf(delta_rad)` with `tanf(delta_rad)` in `Ackermann_ComputeRPM()`.

---

### Mistake 3: Actuator Stalled on Single-Sample ADC Glitch (Bypassing 5-Tick Debounce)
- **What happened:** `ads1115.c` had a 5-tick debounce threshold (`STEER_FAULT_THRESHOLD`), but set `out->valid = 0` on every single failed read. The main loop checked `steer.valid` directly, causing a single dropped I2C transaction to immediately freeze the actuator and reset the PID integral.
- **How it was found:** Logic tracing of `out->valid` assignment vs `main.c` actuator control gate.
- **How it was corrected:** Retained the previous valid steering angles during transient faults and kept `valid = 1` until `fault_runs >= STEER_FAULT_THRESHOLD`.

---

### Mistake 4: Reverse Differential Ratio Distortion from Post-Hoc Clamping
- **What happened:** `Ackermann_ComputeRPM()` properly rescaled both wheel RPMs together when either exceeded `WHEEL_RPM_MAX` (20 RPM), but `_ToThrottle()` independently clamped reverse RPM to `THR_REV_RPM_CAP` (10 RPM). On a sharp reverse turn (e.g. inner wheel 6 RPM, outer wheel 12 RPM), only the outer wheel was clamped, compressing the 2:1 differential ratio down to 1.66:1.
- **How it was found:** Tracing RPM limits and throttle conversion across forward vs reverse modes.
- **How it was corrected:** Passed the active direction/RPM limit into `Ackermann_ComputeRPM()` to scale both wheels down proportionally before throttle generation.

---

### Mistake 5: Hardcoded Magic Number `0.183f` for Reverse Max Velocity
- **What happened:** `v_max_dir` used a bare float literal `0.183f` in `ackermann.c`, which represented $(10\text{ RPM}/60) \times 2\pi R$, decoupling it from `THR_REV_RPM_CAP`.
- **How it was found:** Code review of constant propagation.
- **How it was corrected:** Defined `VMAX_REV_MS` derived explicitly from `THR_REV_RPM_CAP` and `WHEEL_RADIUS_M`.

---

### Mistake 6: Actuator Duty Cycle Shaved to 99.9%
- **What happened:** With `ACT_PWM_ARR = 999`, full 100% duty cycle in STM32 PWM Mode 1 requires `CCR = 1000` (`ARR + 1`). Clamping CCR to `ACT_PWM_ARR` (999) limited output to 99.9%.
- **How it was found:** STM32 Timer PWM compare register behavior analysis.
- **How it was corrected:** Adjusted maximum compare register value to `ACT_PWM_ARR + 1` (1000) when duty cycle is 100%.

---

### Mistake 7: Derivative Kick on Setpoint Changes in Steering PID
- **What happened:** `SteerPID_Update()` calculated derivative on error: $\frac{d(e)}{dt} = \frac{d(\text{target} - \text{actual})}{dt}$. When the transmitter stick was moved quickly, the step-change in `target_deg` caused a massive derivative spike ("derivative kick"), lurching the actuator.
- **How it was found:** Control systems analysis of setpoint step response.
- **How it was corrected:** Switched to **Derivative-on-Measurement**: $\text{derivative} = -\frac{\delta_{\text{actual}} - \delta_{\text{prev\_actual}}}{dt}$.

---

### Note: Potentiometer Raw ADC Calibration Done Off-Board (ESP32 rig)
- **What happened:** Rather than flashing `Rover_closed_loop` and calibrating through the STM32's own `ADS1115_ReadRaw()` + existing PA9→ESP32 debug telemetry link, the raw min/max was captured with a standalone ESP32 + `Adafruit_ADS1X15` sketch wired identically to the final install (same `0x48` address, same AIN0=left/AIN1=right assignment, same 3.3V pot excitation, and — critically — gain forced to `GAIN_ONE` (±4.096V) to match the STM32 firmware's `PGA=001` config word, since the raw ADC code is gain-dependent and the library's default gain, `GAIN_TWOTHIRDS` (±6.144V), would have produced non-portable numbers).
- **Why this is valid:** the ADS1115's raw output is a function only of the analog voltage on the pin and the PGA gain setting — not of which MCU reads it — so with gain and wiring matched, the numbers transfer directly to `ackermann_config.h` without touching the STM32 firmware.
- **Measured raw values (lock-to-lock sweep):**

  | | Left pot (`AIN0`) | Right pot (`AIN1`) |
  |---|---|---|
  | Extreme **left** turn (MAX_RAW) | 15766 | 14279 |
  | Extreme **right** turn (MIN_RAW) | 6813 | 6059 |

  Both channels move the same direction for the same turn (higher raw = left lock), consistent with the sign convention documented in `ackermann_config.h`. Both well inside the `ADC_SANITY_MIN/MAX` (200–32000) guard band. Span differs L=8953 vs R=8220 (~9%), attributed to normal pot-to-pot tolerance — each channel is calibrated independently so this doesn't affect correctness.
- **⚠️ Open item:** the actual mechanical lock-to-lock angle was **not** measured with a protractor — `MAX_STEER_ANGLE_DEG` (45.0°) in `ackermann_config.h` is still the assumed design value, unverified against hardware. If the true lock angle differs, the linear raw→angle mapping will be off even though the raw calibration itself is correct (see architecture.md Phase 4 Step 2).
- **Applied:** `ADC_L_MIN_RAW=6813`, `ADC_L_MAX_RAW=15766`, `ADC_R_MIN_RAW=6059`, `ADC_R_MAX_RAW=14279` in `ackermann_config.h`.

---

### Note: Steering Deadband Widened, Twice — 0.5° → 1.3° → 2.5°
- **What happened:** `STEER_DEADBAND_DEG` first changed `0.5f` → `1.3f` pre-emptively (not yet hardware-tested). After flashing and testing on real hardware, the actuator was confirmed **hunting/oscillating trying to settle at zero** — consistent with the predicted cause: the actuator is 100%-speed bang-bang (no low-speed throttling, see architecture.md §2.1) so it overshoots the deadband window each correction, flips direction, overshoots the other way, repeats.
- **Correction:** widened further to `2.5f` to give enough margin for the actuator's overshoot at full speed / 20 Hz loop reaction time.
- **Applied:** `STEER_DEADBAND_DEG = 2.5f` in `ackermann_config.h`. ⚠️ Not yet re-verified on hardware whether 2.5° fully eliminates the hunting, or whether it needs to go wider still (or whether the real fix is eventually throttling actuator speed near the setpoint instead of widening the band indefinitely).

---
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

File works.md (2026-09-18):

# Works Log — Problems & Precise Solutions

A concise summary of engineering problems encountered and their solutions on the STM32 Agricultural Rover platform.

---

| # | Problem | Root Cause | Precise Solution |
|---|---|---|---|
| 1 | Linker failure on `.ARM.extab` | `(READONLY)` keyword in CubeMX linker script incompatible with GCC 10 | Removed `(READONLY)` from all section definitions in `STM32F411CEUX_FLASH.ld`. |
| 2 | Compile error in `steer_pid.c` | `LOOP_HZ` referenced without including `config.h` | Added `#include "config.h"` in `steer_pid.c`. |
| 3 | Kinematic radius error on sharp turns | `sinf(delta)` used instead of `tanf(delta)` in `Ackermann_ComputeRPM` | Changed turning radius formula to $R_{\text{rear}} = \frac{W_b}{\tan(\delta)}$ in `ackermann.c`. |
| 4 | Steering stalls on transient ADC glitch | `out->valid` set to 0 on single missed read, bypassing 5-tick debounce | Held previous angle and kept `valid=1` until `fault_runs >= STEER_FAULT_THRESHOLD` in `ads1115.c`. |
| 5 | Reverse differential ratio compression | Outer wheel clamped independently in `_ToThrottle` at 10 RPM | Scaled both wheel RPMs down proportionally inside `Ackermann_ComputeRPM` for reverse mode. |
| 6 | Derivative kick on rapid stick movement | PID differentiated on error $(target - actual)$ | Switched PID derivative calculation to derivative-on-measurement in `steer_pid.c`. |
| 7 | Actuator PWM capped at 99.9% | Compare register clamped to ARR (999) instead of ARR+1 (1000) | Allowed `CCR` to reach `ACT_PWM_ARR + 1` at 100% duty cycle in `actuator.c`. |
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

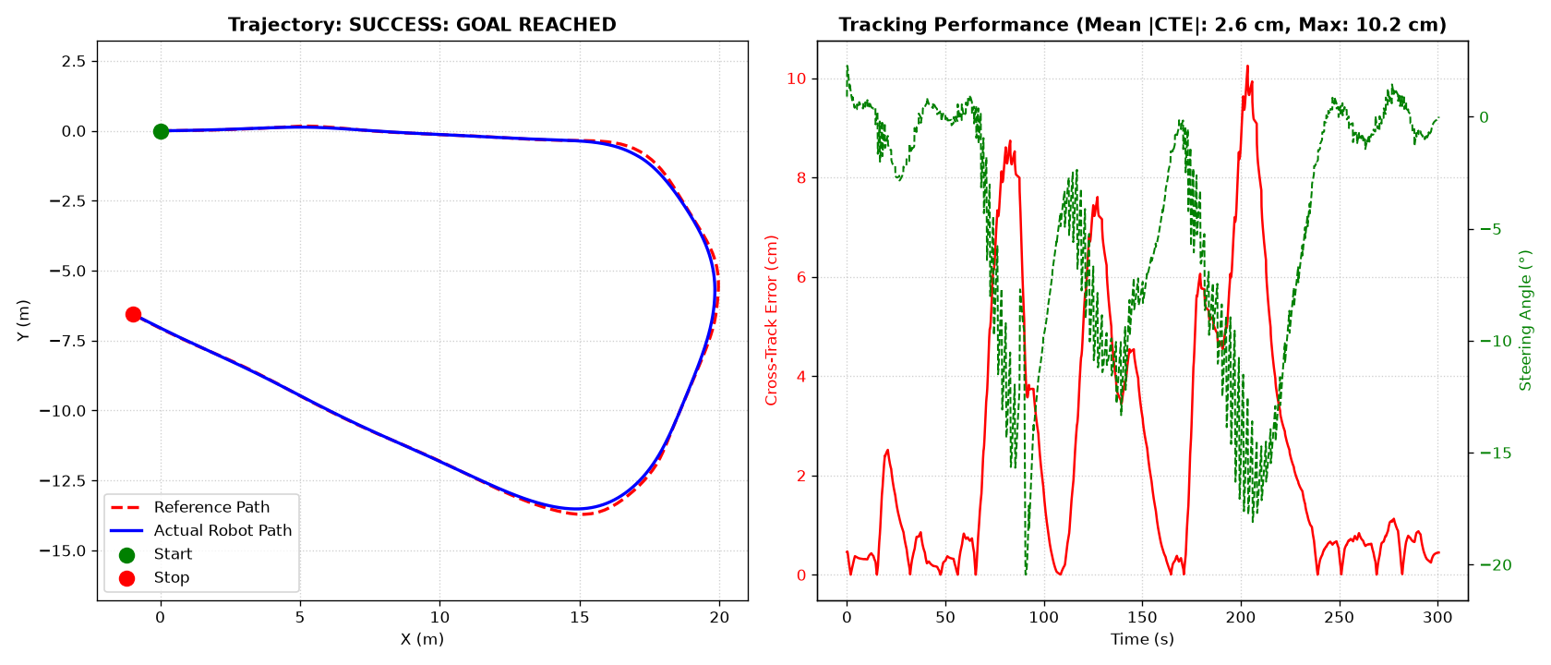
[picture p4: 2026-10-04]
docs/figures/stanley_vs_pure_pursuit.png

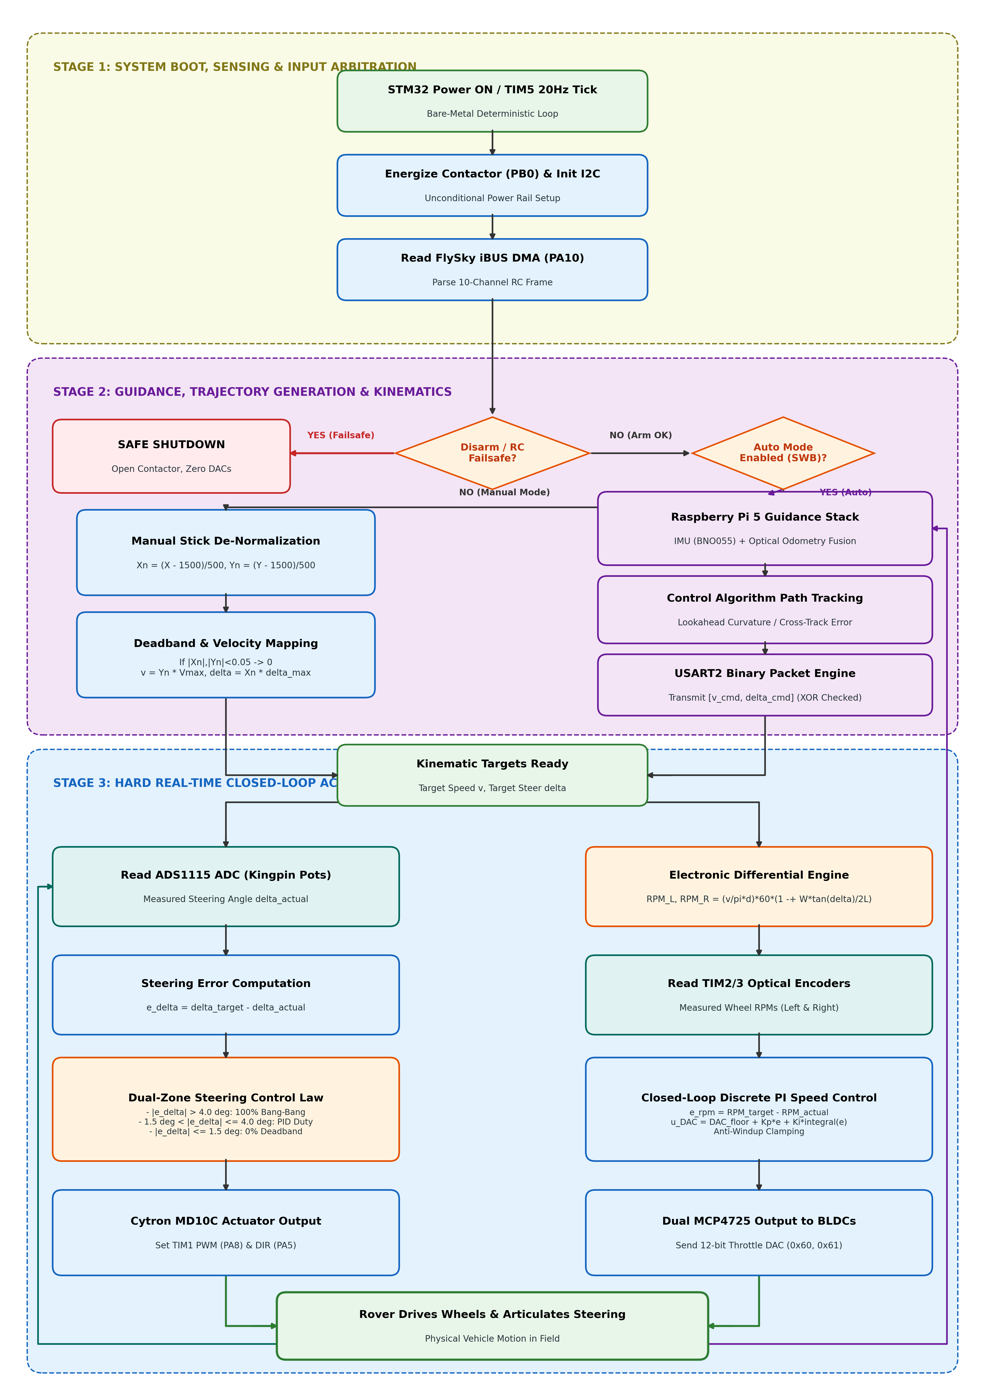
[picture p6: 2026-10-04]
docs/figures/software_flowchart.png

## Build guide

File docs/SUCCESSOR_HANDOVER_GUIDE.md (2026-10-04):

# Agricultural Ackermann Autonomous Rover: Technical Handover & Engineering Guide
**Department of Electrical Engineering, Indian Institute of Technology Palakkad**  
**Author / Outgoing Engineer:** Mr. Jagan J S (*Embedded Engineering Intern*)  
**Target Audience:** Successor Embedded Systems & Robotics Engineer  
**Date of Handover:** September 2026  

---

## Table of Contents
1. [Executive Summary & System Architecture](#1-executive-summary--system-architecture)
2. [Repository & Codebase Directory Map](#2-repository--codebase-directory-map)
3. [Hardware Specifications & Pinout Matrix](#3-hardware-specifications--pinout-matrix)
4. [STM32 Bare-Metal Firmware (`Rover_closed_loop`)](#4-stm32-bare-metal-firmware-rover_closed_loop)
5. [Raspberry Pi 5 Autonomy Stack (`RPi_companion`)](#5-raspberry-pi-5-autonomy-stack-rpi_companion)
6. [Cellular Fleet Tracker & API Stack](#6-cellular-fleet-tracker--api-stack)
7. [Calibration, Tuning & Startup Runbooks](#7-calibration-tuning--startup-runbooks)
8. [Critical Solved Pitfalls & Troubleshooting Matrix](#8-critical-solved-pitfalls--troubleshooting-matrix)
9. [Strategic Engineering Roadmap (Next Priorities)](#9-strategic-engineering-roadmap-next-priorities)

---

## 1. Executive Summary & System Architecture

### 1.1 The Platform Transformation
This project upgraded an agricultural rover from an obsolete **BeagleBone Black open-loop differential-drive** architecture to a robust, distributed **STM32F411 + Raspberry Pi 5 Ackermann steering** architecture.

```
       +-------------------------------------------------------------------+
       |                       POWER SYSTEM (54.6V)                        |
       |  54.6V Battery --> Isolator --> 100A Contactor --> 48V DC Bus     |
       |                                      |                            |
       |                   +------------------+-------------------+        |
       |                   |                                      |        |
       |           48V -> 12V Step-Down                   48V -> 5V Step   |
       |           (Actuator & Driver)                    (Logic & RPi 5)  |
       +-------------------------------------------------------------------+
                                      |
                                      v
       +-------------------------------------------------------------------+
       |                    HIGH-LEVEL COMPUTE & AUTONOMY                  |
       |                                                                   |
       |   +---------------------+             +-----------------------+   |
       |   |  Raspberry Pi 5     |<-- I2C1 ----| BNO055 9-DOF IMU      |   |
       |   |  Autonomy Stack     |             +-----------------------+   |
       |   |  - Guidance / PID   |                                         |
       |   |  - Row-Skip Planner |             +-----------------------+   |
       |   |  - Odom Fusion      |             | 4G Tracker (ESP32)    |   |
       |   +---------------------+             | - Quectel EC200U LTE  |   |
       |              |                        | - Standalone AntiTheft|   |
       |              | UART 115200 (USART2)   +-----------------------+   |
       |              v                                                    |
       +-------------------------------------------------------------------+
                                      |
                                      v
       +-------------------------------------------------------------------+
       |                 LOW-LEVEL REAL-TIME EMBEDDED CORE                 |
       |                                                                   |
       |   +-----------------------------------------------------------+   |
       |   |                 STM32F411CEU6 ("Black Pill")              |   |
       |   |  - 20 Hz Deterministic Loop (TIM5)                        |   |
       |   |  - Closed-Loop PI Wheel Velocity (wheel_pid.c)            |   |
       |   |  - Zoned Linear Actuator Steering (actuator.c)            |   |
       |   |  - Electronic Differential Math                           |   |
       |   |  - Contactor MOSFET Switch & Fault Recovery               |   |
       |   +-----------------------------------------------------------+   |
       |         |          |               |               |              |
       +---------|----------|---------------|---------------|--------------+
                 |          |               |               |
     PWM/DIR (PA8/5)    I2C1 (0x48)     I2C1 (0x60/61)  TIM2/3 Quadrature
                 |          |               |               |
                 v          v               v               v
       +-------------+ +----------+ +---------------+ +------------------+
       | Cytron MD10C| | ADS1115  | | Dual MCP4725  | | YT06-OP-1M Optical|
       | Motor Driver| | 16b ADC  | | 12-bit DACs   | | Wheel Encoders   |
       +-------------+ +----------+ +---------------+ +------------------+
              |              ^              |                 ^
              v              |              v                 |
       +-------------+ +----------+ +---------------+         |
       | PA-12 Linear| | Dual 10k | | Dual BLDC     |---------+
       | Actuator    | | Kingpin  | | Motor Drivers |
       | (Steering)  | | Pots     | | (48V 32A)     |
       +-------------+ +----------+ +---------------+
                                            |
                                            v
                                     +---------------+
                                     | Dual 750W BLDC|
                                     | 20:1 Gearbox  |
                                     +---------------+
```

### 1.2 Core Architectural Philosophy
- **Hard Real-Time Local Safety (STM32):** The STM32 bare-metal firmware runs at 20 Hz. It controls the main contactor, monitors RC failsafes, executes linear actuator positioning, and handles closed-loop PI motor velocity control. If the Raspberry Pi crashes or loses serial communication, the STM32 automatically defaults to safe idle or manual RC control within 500 ms.
- **High-Level Autonomy (Raspberry Pi 5):** The Raspberry Pi handles complex geometric trajectory generation, sensor fusion (IMU + wheel odometry), and path tracking.
- **Autonomous Sub-System Separation:** The IoT cellular security tracker runs completely independently on an ESP32 to guarantee remote telemetry and anti-theft monitoring even if the primary traction system is powered down.

---

## 2. Repository & Codebase Directory Map

All project directories reside in `/home/tuf/Documents/REPORT/`:

```
/home/tuf/Documents/REPORT/
├── Autonomous_Ackermann/
│   └── Rover_closed_loop/       <-- [CRITICAL] Active STM32 Bare-Metal Production Firmware
│       ├── Core/
│       │   ├── Inc/              <-- Headers (main.h, wheel_pid.h, stm32f4xx_it.h)
│       │   └── Src/              <-- Source files (main.c, wheel_pid.c, system_stm32f4xx.c)
│       ├── Drivers/              <-- STM32 HAL and CMSIS Drivers
│       └── Rover_closed_loop.ioc <-- STM32CubeMX Hardware Configuration File
├── RPi_companion/                <-- [CRITICAL] Raspberry Pi 5 Python Autonomy Stack
│   ├── ackermann_controller.py   <-- Path-tracking algorithms (Stanley / Pure Pursuit)
│   ├── make_straight_path.py     <-- Linear benchmarking trajectory generator
│   ├── make_rectangle_path.py    <-- Closed rectangular benchmarking generator
│   ├── make_circle_path.py       <-- Curvature benchmark generator
│   ├── make_lawnmower_path.py    <-- Full boustrophedon coverage path generator
│   ├── make_skip_row_path.py     <-- Headland skip-row agricultural path generator
│   └── rpi_stm32_bridge.py       <-- High-speed binary UART serial interface
├── STM/
│   └── Rover/                    <-- [CRITICAL] Complete KiCad v6 Hardware Schematics & PCB
│       ├── Rover.kicad_pro       <-- KiCad Project File
│       ├── Rover.kicad_sch       <-- System Schematic
│       └── Rover.kicad_pcb       <-- 2-Layer PCB Board Layout
├── UGV_Tracker/                  <-- Standalone Cellular Fleet Tracker Stack
│   ├── firmware_esp32_ec200u/    <-- ESP32 + Quectel EC200U 4G LTE/GNSS Arduino/C++ Firmware
│   ├── backend_server/           <-- FastAPI REST Server & SQLite Database (ugv_tracker.db)
│   └── web_dashboard/            <-- Dark-mode Leaflet.js Real-Time Fleet Map
├── User_API_test/
│   └── rover_api/                <-- Commercial Agricultural REST API & Simulator
├── For_future/
│   └── ROVER_RESEARCH (1).txt    <-- Outgoing research roadmap for RTK-GNSS & e-PTO
├── old_documents/                <-- Legacy BeagleBone Black schematics & flowcharts
├── internship_report.tex         <-- Complete Academic LaTeX Internship Report
└── SUCCESSOR_HANDOVER_GUIDE.md   <-- THIS DOCUMENT
```

---

## 3. Hardware Specifications & Pinout Matrix

### 3.1 Kinematic & Mechanical Parameters
| Parameter | Description | Value | Firmware / Script Reference |
| :--- | :--- | :--- | :--- |
| $L$ | Wheelbase (Front to Rear Axle) | $0.850\text{ m}$ | `ROVER_WHEELBASE_M` |
| $W$ | Track Width (Rear Wheel Stance) | $0.800\text{ m}$ | `ROVER_TRACK_WIDTH_M` |
| $r$ | Drive Wheel Outer Radius | $0.175\text{ m}$ | `ROVER_WHEEL_RADIUS_M` |
| $G$ | Planetary Gearbox Reduction | $20:1$ | Motor Output to Axle |
| $\text{RPM}_{\text{max, wheel}}$ | Maximum Rear Wheel Speed | $25\text{ RPM}$ | Equivalent to 500 RPM motor speed |
| $v_{\text{max}}$ | Maximum Forward Linear Speed | $0.458\text{ m/s}$ ($1.65\text{ km/h}$) | `MAX_LINEAR_VELOCITY` |
| $v_{\text{cruise}}$ | Autonomous Nominal Cruise Speed | $0.240\text{ m/s}$ ($0.86\text{ km/h}$) | Path tracking default |
| $\delta_{\text{max}}$ | Maximum Steering Angle | $\pm 45.0^\circ$ | `STEER_MAX_DEG` |
| $R_{\text{min}}$ | Minimum Turning Radius | $\approx 2.50\text{ m}$ | Non-holonomic steering limit |

---

### 3.2 STM32F411CEU6 Master Pinout Matrix
| Pin Name | Peripheral Function | Hardware Connection | Purpose / Electrical Spec |
| :--- | :--- | :--- | :--- |
| **`PA0`** | `TIM2_CH1` | Optical Encoder Left (CH A) | 32-bit Quadrature Input, 100nF RC filter |
| **`PA1`** | `TIM2_CH2` | Optical Encoder Left (CH B) | 32-bit Quadrature Input, 100nF RC filter |
| **`PA6`** | `TIM3_CH1` | Optical Encoder Right (CH A)| 16-bit Quadrature Input, 100nF RC filter |
| **`PA7`** | `TIM3_CH2` | Optical Encoder Right (CH B)| 16-bit Quadrature Input, 100nF RC filter |
| **`PA8`** | `TIM1_CH1` | Cytron MD10C `PWM` | Linear Actuator Speed (20 kHz PWM) |
| **`PA5`** | `GPIO_Output` | Cytron MD10C `DIR` | Linear Actuator Direction (HIGH/LOW) |
| **`PB8`** | `I2C1_SCL` | I2C Clock Bus | SCL for ADS1115 (`0x48`) & MCP4725 (`0x60/61`) |
| **`PB9`** | `I2C1_SDA` | I2C Data Bus | SDA for ADS1115 (`0x48`) & MCP4725 (`0x60/61`) |
| **`PA10`**| `USART1_RX` | FlySky FS-iA10B `iBUS` | 115200 baud Serial RX (DMA + Idle Line) |
| **`PA9`** | `USART1_TX` | Debug / Sniffer TX | Telemetry output for external debuggers |
| **`PA2`** | `USART2_TX` | Raspberry Pi 5 RX | Binary Command Link (115200 baud, DMA) |
| **`PA3`** | `USART2_RX` | Raspberry Pi 5 TX | Binary Feedback Link (115200 baud, DMA) |
| **`PB0`** | `GPIO_Output` | Contactor Gate MOSFET | Controls 48V 100A DC Main Power Contactor |
| **`PC13`**| `GPIO_Output` | Onboard Blue LED | 1 Hz Heartbeat / Error Blink |

---

## 4. STM32 Bare-Metal Firmware (`Rover_closed_loop`)

### 4.1 Execution Flow & Timing
The core loop executes in [`Autonomous_Ackermann/Rover_closed_loop/Core/Src/main.c`](file:///home/tuf/Documents/REPORT/Autonomous_Ackermann/Rover_closed_loop/Core/Src/main.c):
1. **Hardware Initialization (`0.0 - 0.2s`):**
   - Configures system clocks (100 MHz PLL from 25 MHz HSE).
   - Initializes GPIOs and immediately drives `PB0 = HIGH` to close the main 48V contactor.
   - Starts timers: `TIM1` (Actuator PWM), `TIM2` (Left Encoder), `TIM3` (Right Encoder), `TIM5` (20 Hz loop tick).
   - Initializes `I2C1` and tests connectivity to ADS1115 (`0x48`), Left DAC (`0x60`), and Right DAC (`0x61`).
   - Starts DMA reception on `USART1` (iBUS) and `USART2` (RPi5 link).
2. **20 Hz Control Iteration (Every 50 ms):**
   - **Step 1: Read Feedback:** Reads kingpin potentiometer angles via ADS1115 and updates wheel RPMs from `TIM2`/`TIM3` encoder count deltas.
   - **Step 2: Parse Control Inputs:**
     - Checks iBUS Channel 5 (Autonomous Mode Switch).
     - If `CH5 > 1500`: Mode is **Autonomous** $\rightarrow$ parse target speed and steering angle from Raspberry Pi USART2 packet.
     - If `CH5 <= 1500` or failsafe triggered: Mode is **Manual RC** $\rightarrow$ parse speed from Channel 2 (Throttle) and steering from Channel 1 (Aileron).
   - **Step 3: Steering Control (`actuator.c`):**
     - Compares target steer angle $\delta_{\text{target}}$ against measured angle $\delta_{\text{actual}}$.
     - Calculates linear actuator PWM and direction using the **Dual-Zone Control Algorithm**.
   - **Step 4: Wheel Velocity PI Control (`wheel_pid.c`):**
     - Calculates required individual wheel linear speeds using Ackermann differential geometry:
       $$v_L = v \left(1 - \frac{W}{2L} \tan\delta\right), \quad v_R = v \left(1 + \frac{W}{2L} \tan\delta\right)$$
     - Converts velocities to target RPMs and executes discrete PI velocity control loop.
     - Writes resulting 12-bit values (0–4095) to Left and Right MCP4725 DACs.
   - **Step 5: Telemetry Transmit:** Packages current rover state (Actual $\delta$, Left/Right RPM, Battery Voltage, Mode) and sends via USART2 DMA to Raspberry Pi 5.

---

### 4.2 Closed-Loop PI Wheel Velocity Controller (`wheel_pid.c`)
To overcome planetary gearbox static friction (stiction) and maintain constant speed under load:

```c
// Closed-loop PI parameters (Tuned for 750W BLDC + 20:1 Gearbox)
#define WHEEL_PID_KP            50.0f
#define WHEEL_PID_KI            15.0f
#define THR_FWD_MIN_DAC         1624     // Feedforward stiction overcoming floor (2.0V)
#define THR_REV_MIN_DAC         1624
#define DAC_MAX_LIMIT           4000     // 4.88V safe upper clamp
#define INTEGRAL_WINDUP_LIMIT   800.0f

void Wheel_PID_Compute(WheelPID_t *pid, float target_rpm, float measured_rpm, uint16_t *dac_out) {
    if (target_rpm == 0.0f) {
        pid->integral = 0.0f;
        *dac_out = 0;
        return;
    }
    
    float error = target_rpm - measured_rpm;
    pid->integral += error * 0.050f; // dt = 50ms (20Hz)
    
    // Anti-windup clamping
    if (pid->integral > INTEGRAL_WINDUP_LIMIT) pid->integral = INTEGRAL_WINDUP_LIMIT;
    if (pid->integral < -INTEGRAL_WINDUP_LIMIT) pid->integral = -INTEGRAL_WINDUP_LIMIT;
    
    float control_val = (WHEEL_PID_KP * error) + (WHEEL_PID_KI * pid->integral);
    
    // Combine feedforward friction floor + PI correction
    int32_t output = THR_FWD_MIN_DAC + (int32_t)control_val;
    if (output < THR_FWD_MIN_DAC) output = THR_FWD_MIN_DAC;
    if (output > DAC_MAX_LIMIT)   output = DAC_MAX_LIMIT;
    
    *dac_out = (uint16_t)output;
}
```

---

### 4.3 Dual-Zone Steering Control Law (`actuator.c`)
To avoid linear actuator limit-cycle oscillation around the mechanical deadband:
- **Zone 1 ($|\Delta\delta| > 4.0^\circ$):** Bang-bang maximum duty ($100\%$) for high slew rate.
- **Zone 2 ($1.5^\circ < |\Delta\delta| \le 4.0^\circ$):** Scaled proportional duty ($40\% - 75\%$).
- **Deadband ($|\Delta\delta| \le 1.5^\circ$):** Duty set strictly to $0\%$ (`ACT_MIN_DUTY_PCT = 0.0f`).

---

## 5. Raspberry Pi 5 Autonomy Stack (`RPi_companion`)

### 5.1 Software Setup & Environment
The Raspberry Pi 5 runs Raspberry Pi OS (64-bit). The companion stack resides in `/home/tuf/Documents/REPORT/RPi_companion`.

To prepare the Python virtual environment:
```bash
cd /home/tuf/Documents/REPORT/RPi_companion
python3 -m venv venv
source venv/bin/activate
pip install numpy scipy pyserial smbus2
```

---

### 5.2 Serial Protocol Specification (STM32 $\longleftrightarrow$ RPi 5)
Communication runs on `USART2` (`/dev/ttyAMA0` on RPi 5) at **115200 baud, 8N1**.

#### A. Command Packet (RPi 5 $\rightarrow$ STM32) — Sent at 20 Hz:
| Byte Index | Field | Type | Description |
| :--- | :--- | :--- | :--- |
| `0` | Header 1 | `uint8_t` | `0xAA` |
| `1` | Header 2 | `uint8_t` | `0x55` |
| `2` | Packet Type | `uint8_t` | `0x01` (Velocity & Steering Command) |
| `3-4` | Target Speed ($v$) | `int16_t` | Speed in $\text{mm/s}$ (e.g., $240 = 0.24\text{ m/s}$) |
| `5-6` | Target Steer ($\delta$)| `int16_t` | Angle in centidegrees (e.g., $1520 = +15.20^\circ$) |
| `7` | Autonomous Enable | `uint8_t` | `1` = Autonomous control active, `0` = Standby |
| `8` | Checksum | `uint8_t` | Bitwise XOR of Bytes 2 through 7 |

#### B. Telemetry Packet (STM32 $\rightarrow$ RPi 5) — Received at 20 Hz:
| Byte Index | Field | Type | Description |
| :--- | :--- | :--- | :--- |
| `0` | Header 1 | `uint8_t` | `0xAA` |
| `1` | Header 2 | `uint8_t` | `0x55` |
| `2` | Packet Type | `uint8_t` | `0x81` (Rover State Telemetry) |
| `3-4` | Measured Steer ($\delta$) | `int16_t` | Kingpin angle in centidegrees |
| `5-6` | Left Wheel Speed | `int16_t` | Measured Left RPM $\times 10$ |
| `7-8` | Right Wheel Speed| `int16_t` | Measured Right RPM $\times 10$ |
| `9-10`| Battery Voltage | `uint16_t`| Battery bus voltage in mV ($54600 = 54.6\text{V}$) |
| `11` | Rover State Flags| `uint8_t` | Bit 0: Contactor closed, Bit 1: Auto mode, Bit 2: Failsafe |
| `12` | Checksum | `uint8_t` | Bitwise XOR of Bytes 2 through 11 |

---

### 5.3 Agricultural Trajectory Generators & Execution
All path scripts generate standard waypoint CSV files formatted as `[x_m, y_m, speed_mps, target_steer_deg]`:

1. **Straight Benchmark Run:**
   ```bash
   python make_straight_path.py --length 20.0 --speed 0.25 --output straight_20m.csv
   python ackermann_controller.py --path straight_20m.csv --port /dev/ttyAMA0
   ```
2. **Headland Skip-Row Agricultural Coverage:**
   Generates smooth, non-holonomic turns between non-adjacent crop rows (Row $1 \rightarrow 3 \rightarrow 5 \rightarrow 2 \rightarrow 4$):
   ```bash
   python make_skip_row_path.py --rows 6 --row_len 30.0 --row_spacing 1.2 --turn_radius 2.6 --output skip_row_field.csv
   python ackermann_controller.py --path skip_row_field.csv --port /dev/ttyAMA0
   ```

---

## 6. Cellular Fleet Tracker & API Stack

### 6.1 ESP32 Tracker Architecture (`UGV_Tracker`)
The tracker operates independently on a custom ESP32 board paired with a **Quectel EC200U 4G LTE/GNSS module**.
- **Location:** [`UGV_Tracker/firmware_esp32_ec200u/`](file:///home/tuf/Documents/REPORT/UGV_Tracker/firmware_esp32_ec200u)
- **Operation:** Transmits JSON telemetry via HTTP POST over cellular 4G every 5 seconds to `/api/v1/telemetry`.

### 6.2 Starting the Cloud Backend & Web Dashboard
```bash
cd /home/tuf/Documents/REPORT/UGV_Tracker/backend_server
# Start FastAPI backend on port 8000
python3 -m venv venv && source venv/bin/activate
pip install fastapi uvicorn sqlite3 pydantic
uvicorn main:app --host 0.0.0.0 --port 8000 --reload
```
Open a browser to `http://<server-ip>:8000/dashboard` to view the Leaflet real-time dark-mode map.

---

## 7. Calibration, Tuning & Startup Runbooks

### 7.1 Front Steering Potentiometer Calibration Procedure
Before operating the rover, calibrate the front kingpin angle feedback:
1. **Mechanical Centering:**
   - Power off the traction system.
   - Manually adjust the steering linkage until both front wheels are exactly parallel to the chassis centerline ($0.0^\circ$).
2. **ADC Zero Reading:**
   - Read the ADS1115 single-ended channel `AIN0` voltage via I2C.
   - Note the center voltage $V_{\text{center}}$ (nominally $\approx 2.50\text{V}$, raw $\text{ADC} \approx 13200$).
3. **Full Lock Verification:**
   - Turn steering to full Left Lock ($+45.0^\circ$): Record $V_{\text{left}}$ ($\approx 4.10\text{V}$).
   - Turn steering to full Right Lock ($-45.0^\circ$): Record $V_{\text{right}}$ ($\approx 0.90\text{V}$).
4. **Update Scale Constants in `actuator.h`:**
   ```c
   #define STEER_POT_CENTER_V      2.500f
   #define STEER_POT_VOLTS_PER_DEG 0.0355f // (V_left - V_right) / 90.0 deg
   ```

---

### 7.2 Field Power-Up Sequence (Checklist)
1. **Physical Pre-Flight Check:**
   - Verify tire pressures (28 PSI).
   - Check steering linkage tie-rods and kingpin bearings for mechanical play.
   - Confirm optical encoder disc alignment (clear of dirt and debris).
2. **Electrical Power-On:**
   - Turn the **Manual Battery Isolator Switch** to ON.
   - Power on the FlySky RC Transmitter. Verify Channel 5 (Auto switch) is in the **DOWN (MANUAL)** position.
   - Turn on the logic power switch.
   - Observe the STM32 Blue LED (`PC13`):
     - Solid for 0.5s $\rightarrow$ Blinking steadily at 1 Hz indicates normal operation.
     - You will hear an audible `CLICK` as the 100A main DC contactor energizes.
3. **Manual RC Verification:**
   - Gently push RC Throttle: Both rear wheels must turn forward synchronously.
   - Move Steering stick Left/Right: Linear actuator must articulate front wheels smoothly without buzzing or limit-cycling.
4. **Autonomous Mode Handover:**
   - Boot Raspberry Pi 5 and launch `ackermann_controller.py`.
   - Confirm serial handshake: The terminal will report `[STM32 LINK] Connected | Batt: 54.2V | Steer: 0.1 deg`.
   - Flip FlySky Channel 5 to **UP (AUTO)**. The rover will begin autonomous waypoint tracking.
   - **Emergency Stop:** Flipping Channel 5 DOWN immediately returns control to manual RC; shutting off the transmitter triggers hardware failsafe neutral within 100 ms.

---

## 8. Critical Solved Pitfalls & Troubleshooting Matrix

| Symptom / Failure Mode | Root Cause Identified | Engineering Solution Implemented |
| :--- | :--- | :--- |
| **System freezes on cold boot; DACs unresponsive** | `Motor_Init()` tried to query I2C DACs before the 48V contactor closed, leaving DACs unpowered on an unpowered sub-rail. | Contactor switch (`PB0`) is now energized **unconditionally first**. Added `_RecoverI2cBus()` (9 clock pulses on `PB8`) before I2C initialization. |
| **Front steering oscillates violently around $0^\circ$** | Minimum PWM floor (`ACT_MIN_DUTY_PCT`) was set to $70\%$, causing the linear actuator to overshoot the deadband continuously. | Set `ACT_MIN_DUTY_PCT = 0.0f` and implemented dual-zone control (100% duty $>4^\circ$, PID $\le 4^\circ$, $0\%$ within $1.5^\circ$). |
| **Rover stalls at low speeds or surges unpredictably** | BLDC motor controller deadband and 20:1 planetary gearbox static friction (stiction). | Implemented closed-loop PI speed control (`wheel_pid.c`) with a feedforward friction overcoming baseline (`THR_FWD_MIN_DAC = 1624`). |
| **Encoder RPM jumps randomly in electrical noise** | Motor driver switching noise induced spurious voltage spikes on high-impedance optical encoder wires. | Added $100\text{ nF}$ ceramic low-pass filter capacitors between encoder signal lines (A/B) and GND directly at the STM32 screw terminals. |
| **Loss of Raspberry Pi serial packets under CPU load** | OS kernel context switches delayed standard user-space `read()` calls on UART. | Implemented STM32 USART2 DMA circular ring-buffer reception with Idle Line Interrupt detection (`IDLEIE`). |

---

## 9. Strategic Engineering Roadmap (Next Priorities)

Based on field trials and the research notes in [`For_future/ROVER_RESEARCH (1).txt`](file:///home/tuf/Documents/REPORT/For_future/ROVER_RESEARCH%20%281%29.txt), the recommended next engineering phases are:

1. **Centimeter-Level RTK GNSS + EKF Fusion:**
   - Interface a dual-frequency RTK GNSS receiver (e.g., u-blox ZED-F9P) over UART to the Raspberry Pi 5.
   - Implement an Extended Kalman Filter (EKF) using `robot_localization` to fuse RTK GNSS positions with wheel encoder odometry and BNO055 IMU heading.
2. **Electronic Power Take-Off (e-PTO) Implementation:**
   - Design an auxiliary 48V / 12V high-power solid-state relay switching board controlled by spare STM32 pins (`PB12`, `PB13`).
   - Enables companion-commanded power to rotary weeders, seeders, and pesticide spray booms.
3. **Perception & Crop-Row Visual Servoing:**
   - Mount an Intel RealSense D435i or Luxonis OAK-D stereo camera on the front mast.
   - Implement an OpenCV / YOLO-based crop-line detection pipeline to dynamically center the rover between plant canopies without relying solely on GPS coordinates.

---
*For any hardware questions or schematic clarifications, refer to the KiCad files in `STM/Rover` and the complete academic thesis in `internship_report.tex`.*

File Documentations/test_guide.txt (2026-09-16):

Straight line (10m) — the simplest case

Command:
python3 -c "import waypoints as wp; wp.save_csv(wp.generate_straight_line(10.0), 'paths/straight_10m.csv')"
The entire resulting file:
x,y,speed_mps
0.000,0.000,0.200
1.000,0.000,0.200
2.000,0.000,0.200
...
10.000,0.000,0.200
That's it — 11 rows. x counts up from 0 to 10 in 1m steps (our locked-in straight-line spacing), y stays 0 the whole way (it's a straight line, no sideways movement), speed_mps is the target speed at each point (0.2 m/s, the placeholder cruise speed — flag if you want this changed). This file is the path — nothing more abstract than a list of points.

Rectangle (8×6)

python3 -c "import waypoints as wp; wp.save_csv(wp.generate_rectangle(8.0, 6.0), 'paths/rectangle_8x6.csv')"
Same idea, walking the perimeter: (0,0) → (8,0) → (8,6) → (0,6) → back to (0,0), with points filled in every 1m along each edge (29 rows total).

Circle (⌀6m)

python3 -c "import waypoints as wp; wp.save_csv(wp.generate_circle(6.0), 'paths/circle_d6m.csv')"
x,y,speed_mps
0.000,0.000,0.200
0.299,0.015,0.200
0.594,0.059,0.200
0.884,0.133,0.200
...
Here x and y both change every row — that's what makes it a curve instead of a line. It starts at (0,0) moving along +X, curves left (our ccw=True default), and after 64 points ends back at (0,0) — a closed loop.

Lawnmower (4 rows of 6m)

python3 -c "import waypoints as wp; wp.save_csv(wp.generate_lawnmower(6.0, 4), 'paths/lawnmower_6m_x4.csv')"
Same idea, but it's rows + turns stitched together: drive 6m along +X, curve 180° (the 1.6m-wide turn we discussed), drive 6m back along -X one row over, curve again, etc. — 49 points total for 4 rows.

, can we make 4 different python scripts for the 4 shapes, like when we call python3 script_name.py(name the script based on the shape creating) it will ask for
  the dimesions like for straight line the length, for rectangle the length and breadth, for circle the diameter, for lawnmover the row length and number of rows. and save the files with
  appropriate filename with that can match the mission.py with suffixes.

================================================================================
ADDENDUM — 2026-09-16 (appended, nothing above this line was changed)
================================================================================

- The 4-scripts request above was built: `make_straight_path.py`,
  `make_rectangle_path.py`, `make_circle_path.py`, `make_lawnmower_path.py`
  (thin interactive wrappers over `waypoints.py`, prompting for exactly the
  dimensions described above via a shared `path_prompts.py` helper), saving
  to `paths/<shape>_<dims>.csv`. Verified against the `python3 -c ...`
  one-liners above — same waypoint counts (11/29/64/49).
- The `0.200` speed_mps values in every example above are OUT OF DATE — that
  was an early placeholder. The actual value has moved twice since:
  0.2 -> 0.12 (felt too fast in the field) -> 0.24 (current, doubled once
  the closed-loop wheel-speed PI was field-verified working). The current
  value is `CRUISE_SPEED_MPS` in `RPi_companion/rover_config.py` — treat
  that file as the source of truth, not the numbers in this example.
- Full detail on both of the above, and everything since, is in
  `architecture.md`/`scratchpad.md`/`works.md` at the project root, and the
  settled-reference version in `Rover_study.md` §14.

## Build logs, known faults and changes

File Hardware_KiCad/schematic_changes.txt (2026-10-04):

===============================================================================
ROVER SYSTEM - SCHEMATIC CHANGES LOG
===============================================================================
Project: Rover KiCad Design (/home/robin/Documents/Kicad/Rover)
Schematic: kicad_setup.kicad_sch
Tool Chain: KiCad Flatpak CLI 10.0.4

CHANGES LOG (EDIT 1: YT06-OP-1M ENCODER INTEGRATION):
-------------------------------------------------------------------------------
1. SYMBOL DEFINITION:
   - Added custom library symbol 'Encoder:YT06-OP-1M' inside lib_symbols block.

2. PRECISE COMPONENT PLACEMENT:
   - Left Wheel Encoder (ENC1):
     * Position: (45.72mm, 165.10mm) on canvas, directly adjacent to BBB M1 eQEP1 pins.
   - Right Wheel Encoder (ENC2):
     * Position: (193.04mm, 101.60mm, Mirrored X) on canvas, directly facing BBB M1 eQEP2b pins.
   - Noise Filtering Capacitors (Value: 104 / 100nF):
     * C5: (73.66mm, 172.72mm) - Filters Left Phase A (P8_35)
     * C6: (68.58mm, 172.72mm) - Filters Left Phase B (P8_33)
     * C7: (167.64mm, 109.22mm) - Filters Right Phase A (P8_12)
     * C8: (162.56mm, 109.22mm) - Filters Right Phase B (P8_11)

3. DIRECT WIRE & NET CONNECTIONS:
   - Left Encoder ENC1 -> BeagleBone Black M1:
     * Pin 3 (Phase A) -> Wired directly to Pin P8_35 (81.28mm, 166.37mm), Label: ENC_L_PHASE_A
     * Pin 4 (Phase B) -> Wired directly to Pin P8_33 (81.28mm, 163.83mm), Label: ENC_L_PHASE_B
     * Pin 1 (VCC)     -> Wired to +5V net
     * Pin 2 (GND)     -> Wired to power:GND
   - Right Encoder ENC2 -> BeagleBone Black M1:
     * Pin 3 (Phase A) -> Wired directly to Pin P8_12 (152.40mm, 102.87mm), Label: ENC_R_PHASE_A
     * Pin 4 (Phase B) -> Wired directly to Pin P8_11 (152.40mm, 100.33mm), Label: ENC_R_PHASE_B
     * Pin 1 (VCC)     -> Wired to +5V net
     * Pin 2 (GND)     -> Wired to power:GND
   - Power Supply Converter U6:
     * Pin 3 (VOUT+) -> Connected to +5V net
     * Pin 4 (VOUT-) -> Connected to GND net

4. VISUAL RENDERING & VERIFICATION:
   - Exported schematic to SVG: flatpak run --command=kicad-cli org.kicad.KiCad sch export svg ...
   - Exported schematic to PDF: flatpak run --command=kicad-cli org.kicad.KiCad sch export pdf ...
   - Passed KiCad Flatpak CLI plotting checks cleanly.
===============================================================================

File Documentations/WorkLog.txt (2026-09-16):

    ================================================================================
  AGRICULTURE ROVER — STM32 MIGRATION WORK LOG
  Project   : Agriculture Rover (BeagleBone Black → STM32F411CEU6)
  Engineer  : Suyash (Robotics Engineer)
  Platform  : STM32F411CEU6 (Black Pill), STM32CubeIDE / CubeMX / CubeProgrammer
  Log Start : Session 1 (Previous context)
  Log End   : Session 3 (Current context, 2026-07-30)
================================================================================

━━━━━━━━━━━━━━━━━━━━━━━━━━━━━━━━━━━━━━━━━━━━━━━━━━━━━━━━━━━━━━━━━━━━━━━━━━━━━━
BACKGROUND / PROBLEM STATEMENT
━━━━━━━━━━━━━━━━━━━━━━━━━━━━━━━━━━━━━━━━━━━━━━━━━━━━━━━━━━━━━━━━━━━━━━━━━━━━━━

The Agriculture Rover was originally controlled by a BeagleBone Black (BBB)
running Debian Linux with Python 3.11. In field conditions (high ambient
temperatures), the BBB would freeze and become unresponsive, making the rover
unsafe to operate.

Decision: Replace the BBB with an STM32F411CEU6 (Black Pill) — a Cortex-M4
microcontroller running at 100 MHz, far more thermally robust, with no OS
overhead, deterministic real-time behaviour, and low power draw.

This log documents every step taken from initial code understanding through
hardware bring-up, module implementation, debugging, and first successful
hardware tests.

━━━━━━━━━━━━━━━━━━━━━━━━━━━━━━━━━━━━━━━━━━━━━━━━━━━━━━━━━━━━━━━━━━━━━━━━━━━━━━
SECTION 1 — BBB SYSTEM UNDERSTANDING
━━━━━━━━━━━━━━━━━━━━━━━━━━━━━━━━━━━━━━━━━━━━━━━━━━━━━━━━━━━━━━━━━━━━━━━━━━━━━━

Reviewed all existing BBB source files in /home/suyash/stm/BBB/ to build a
complete understanding of the rover before writing any STM32 code.

--- Hardware Inventory (BBB side) ---

  Component         | Detail
  ------------------|----------------------------------------------------------
  RC Receiver       | FlySky FS-i6X + FS-iA6B, iBUS, UART5 /dev/ttyS5, 115200
  Motor DAC (L)     | MCP4725, I2C Bus 2, address 0x61, 12-bit (0–4095)
  Motor DAC (R)     | MCP4725, I2C Bus 2, address 0x60, 12-bit (0–4095)
  Rev GPIO Left     | P8_7
  Rev GPIO Right    | P8_9
  Brake GPIO Left   | P8_8
  Brake GPIO Right  | P8_10
  Contactor         | P8_14 (arms/disarms main motor power)
  IMU               | BNO055, I2C Bus 2 (P9_19 SCL, P9_20 SDA), Euler+9-axis
  Encoders          | YT06-OP-600B, 600 PPR quadrature, on WHEEL SHAFT (post
                    | gearbox). Left: P8_35/P8_33, Right: P8_12/P8_11.
                    | External 4.2 kΩ pull-ups on each phase to 3.3 V.
  GPS               | u-blox ZED-F9P RTK, /dev/ttyACM0, 115200 baud
  WiFi              | USB RTL8188FU + Tailscale VPN

--- Drive Parameters ---

  Wheel radius R        = 0.175 m
  Track width L         = 0.60 m
  Max linear vel Vmax   = 0.366 m/s
  Max angular vel Wmax  = 1.22 rad/s
  Motor max RPM         = 400
  Gear ratio            = 1:20
  Wheel max RPM         = 20 (400 / 20)

--- RC Channel Map (FS-i6X) ---

  CH0 (IBUS_CH_X)  : Right stick left/right  — Steering
  CH1 (IBUS_CH_Y)  : Right stick up/down     — Throttle
  CH4 (SWC)        : 3-position switch        — Forward speed cap (30/60/100%)
  CH5 (SWD)        : 2-position switch        — Arm / Disarm contactor
  CH6 (SWB)        : 2-position switch        — Reverse speed cap (60/100%)

--- BBB Software Architecture ---

  main.py                          — 20 Hz control loop
  pipeline.py                      — RC → motion state → wheel RPMs
  config.py                        — All tunables & pin assignments
  drivers/flysky_receiver.py       — iBUS frame parser (pyserial)
  drivers/motor_controller.py      — Open-loop: I2C DAC (smbus2) + GPIO
  drivers/motor_controller_closed_loop.py — PID closed-loop controller
  utils/kinematics.py              — Differential drive (V,W) → (rpm_L, rpm_R)
  Systemd service → startup.sh → main.py
  UDP telemetry on localhost:5005

━━━━━━━━━━━━━━━━━━━━━━━━━━━━━━━━━━━━━━━━━━━━━━━━━━━━━━━━━━━━━━━━━━━━━━━━━━━━━━
SECTION 2 — STM32 PIN & PERIPHERAL PLANNING
━━━━━━━━━━━━━━━━━━━━━━━━━━━━━━━━━━━━━━━━━━━━━━━━━━━━━━━━━━━━━━━━━━━━━━━━━━━━━━

Mapped all BBB peripherals to STM32F411CEU6 pins. Key decisions:

--- Pin Assignment ---

  [CORRECTED 2026-07-30 — this table previously did not match the actual
   generated code (main.h / Rover.ioc). PB3/PB5 were tried briefly for a
   redundant right-encoder B-phase wiring, then removed in favor of PA1/PA7
   — the table below was never updated after that. Verified directly
   against Core/Inc/main.h and Rover.ioc, which are the ground truth.]

  Peripheral       | STM32 Pin  | Mode / Timer
  -----------------|------------|----------------------------------------------
  USART1 RX (iBUS) | PA10       | USART1 RX, 115200, DMA2 Stream2 Ch4
  I2C1 SCL (DAC)   | PB6        | I2C1 (MCP4725 DAC pair)
  I2C1 SDA (DAC)   | PB7        | I2C1
  Encoder L A/B    | PA0/PA1    | TIM2 CH1/CH2 — Combined Encoder Mode
  Encoder R A/B    | PA6/PA7    | TIM3 CH1/CH2 — Combined Encoder Mode
  Contactor        | PB0        | GPIO Output (optocoupler)
  Rev Left         | PB1        | GPIO Output
  Brake Left       | PB10       | GPIO Output
  Brake Right      | PB12       | GPIO Output
  Rev Right        | PB13       | GPIO Output
  TIM5             | (internal) | 32-bit us counter for delays & timestamps
  TIM4             | (internal) | 20 Hz main loop timer (50 ms period)

--- Encoder Strategy Decision ---

  Considered three approaches:
    1. Encoder Mode (counting edges) — rejected: at 20 RPM wheel shaft,
       only ~40 counts per 50 ms loop cycle → too coarse for PID.
    2. Input Capture — selected: measures period between pulses; gives
       sub-0.1 RPM resolution regardless of wheel speed.
    3. Interrupt-based — similar to input capture but simpler.

  Final choice: TIM2/TIM3 in Combined Encoder Mode TI1+TI2 (quadrature),
  with TIM3 overflow interrupt to handle slow/stopped detection. RPM
  computed from edge period measured against TIM5 microsecond counter.

  Encoder filter set to value 9 in CubeMX to debounce 4.2 kΩ pull-up
  encoder signals (removes switch bounce / EMI spikes in agricultural env).
  External pull-ups confirmed: 4.2 kΩ on each phase to 3.3 V (user-provided).

--- I2C Configuration ---

  I2C1 for MCP4725 DACs (PB6/PB7).
  Pull-up resistors on PCB: 4.7 kΩ to 3.3 V.
  Initial setting: 400 kHz (Fast Mode).
  LATER CHANGED to 100 kHz — see Section 5 for reason.

--- CubeMX Settings Applied by User ---

  TIM2, TIM3 : Encoder Mode, TI1 Input Filter = 9
  TIM5       : Internal Clock, 32-bit counter, prescaler = 99 → 1 MHz (1 µs)
  TIM4       : Internal Clock, prescaler gives 20 Hz period
  USART1     : 115200 baud, 8N1, DMA RX enabled (added later)
  I2C1       : Standard mode 100 kHz (corrected from 400 kHz)
  GPIO       : Contactor, Rev L/R, Brake L/R as Push-Pull Output
  DMA2       : Stream 2, Channel 4 — USART1 RX (added in second pass)

━━━━━━━━━━━━━━━━━━━━━━━━━━━━━━━━━━━━━━━━━━━━━━━━━━━━━━━━━━━━━━━━━━━━━━━━━━━━━━
SECTION 3 — STM32 MODULE IMPLEMENTATION (All Modules Written)
━━━━━━━━━━━━━━━━━━━━━━━━━━━━━━━━━━━━━━━━━━━━━━━━━━━━━━━━━━━━━━━━━━━━━━━━━━━━━━

All source and header files created under /home/suyash/stm/Rover/Core/:

--- 3.1  config.h  (Core/Inc/config.h) ---

  Central configuration header — mirrors BBB config.py in C #defines.
  Contains: geometry, motor/gearbox params, encoder constants, control
  tuning (DEADBAND, EPSILON, MIN_RATIO, SPOT_RPM), timing constants,
  DAC addresses (0x60 / 0x61), iBUS protocol constants, channel map,
  switch thresholds (SWC/SWD/SWB), and motor direction multipliers.

  Key constants:
    DAC_LEFT_ADDR   0x61
    DAC_RIGHT_ADDR  0x60
    DAC_MAX         4095
    IBUS_FRAME_LEN  32
    IBUS_CH_X       0
    IBUS_CH_Y       1
    IBUS_CH_SWC     4
    IBUS_CH_SWD     5
    IBUS_CH_SWB     6
    RC_TIMEOUT_US   400000  (400 ms no-frame → RC lost)
    LOOP_HZ         20
    LOOP_PERIOD_US  50000

--- 3.2  motor.c / motor.h  (Core/Src/motor.c, Core/Inc/motor.h) ---

  Replaces BBB motor_controller.py + smbus2 + Adafruit_BBIO.

  Functions implemented:
    Motor_Init()          — Set all GPIOs low, DAC to zero, clear state
    Motor_Energize()      — Pull Contactor GPIO high, 500 ms settle delay
    Motor_Deenergize()    — Zero DACs, pull Contactor GPIO low
    Motor_SetSpeeds()     — Direction change detection, GPIO toggling,
                            brake release, DAC write with 20 ms sequence delay
    Motor_Brake()         — Zero DACs, assert brake GPIOs
    Motor_Stop()          — Zero DACs, release brake GPIOs (coast)
    Motor_BrakeThenReverse() — 500 ms brake → call SetSpeeds for reverse
    Motor_IsArmed()       — Returns armed state
    Motor_WasReversing()  — Returns reversal state flag

  _WriteDac() — Private I2C helper:
    Sends MCP4725 "Write DAC Register" command (3 bytes):
      buf[0] = 0x40  (command byte, no EEPROM write)
      buf[1] = D[11:4]
      buf[2] = D[3:0] << 4
    Using HAL_I2C_Master_Transmit, addr << 1 (7-bit shift), 50 ms timeout.

  _DelayUs() — Busy-wait using TIM5 CNT register (1 µs resolution).

--- 3.3  encoder.c / encoder.h  (Core/Src/encoder.c, Core/Inc/encoder.h) ---

  Replaces BBB eQEP counter reading.

  Method: Period-based RPM measurement using TIM2 (left) and TIM3 (right)
  in Encoder Mode for direction, with edge timestamps from TIM5 for RPM.
  TIM3 overflow callback (Encoder_TIM3_OvfCallback) handles stopped detection.

  Functions:
    Encoder_Init()              — Reset state, start TIM2/TIM3 encoders
    Encoder_GetRPM_Left()       — Return latest left wheel RPM (signed)
    Encoder_GetRPM_Right()      — Return latest right wheel RPM (signed)
    Encoder_TIM3_OvfCallback()  — Called from TIM3 IRQ to detect motor stop

--- 3.4  ibus.c / ibus.h  (Core/Src/ibus.c, Core/Inc/ibus.h) ---

  Replaces BBB flysky_receiver.py + pyserial.

  Protocol: 32-byte iBUS frames at 115200 baud.
  Header: [0x20, 0x40]. 10 channels × 2 bytes (little-endian). 2-byte checksum.
  Checksum: 0xFFFF − sum of first 30 bytes.

  Implementation uses DMA + UART IDLE interrupt:
    - HAL_UART_Receive_DMA() fills dma_buf[32] in background
    - UART IDLE interrupt fires when frame gap detected
    - IBUS_IdleCallback() stops DMA, parses frame, restarts DMA

  Functions:
    IBUS_Init()               — Enable IDLE IT, start DMA receive
    IBUS_IdleCallback()       — Parse frame on idle line detection
    IBUS_GetChannels()        — Return latest channel array (IRQ-safe copy)
    IBUS_IsSignalOk()         — Returns 1 if frame received within 400 ms
    IBUS_GetXn()              — Normalised steering (-1.0 to +1.0)
    IBUS_GetYn()              — Normalised throttle (-1.0 to +1.0)
    IBUS_GetFwdSpeedLimit()   — SWC mapped to 0.30/0.60/1.00
    IBUS_GetRevSpeedLimit()   — SWB mapped to 0.60/1.00
    IBUS_IsSWD_On()           — SWD arm/disarm toggle (threshold 1450)

--- 3.5  pipeline.c / pipeline.h  (Core/Src/pipeline.c, Core/Inc/pipeline.h) ---

  Replaces BBB pipeline.py.
  Implements differential drive mixer:
    (Xn, Yn) → motion state → (rpm_L, rpm_R, dac_L, dac_R)
  States: FORWARD, REVERSE, SPOT_TURN, BRAKE, STOP
  Applies SWC/SWB speed caps, EPSILON steering curve, MIN_RATIO inner wheel.

--- 3.6  main.c control loop  (Core/Src/main.c) ---

  20 Hz loop driven by TIM4 period interrupt.
  Loop body:
    1. Read IBUS channels
    2. Check SWD → arm/disarm contactor (with debounce)
    3. If armed & signal OK → run pipeline → Motor_SetSpeeds / Motor_Brake
    4. If RC lost → Motor_Brake (failsafe)
    5. Read encoders (for future PID / telemetry)

  Initialisation sequence (USER CODE BEGIN 2):
    Motor_Init()
    Encoder_Init()
    IBUS_Init()
    Motor_Energize()              ← auto-arm on boot
    last_contactor_ts = TIM5->CNT

━━━━━━━━━━━━━━━━━━━━━━━━━━━━━━━━━━━━━━━━━━━━━━━━━━━━━━━━━━━━━━━━━━━━━━━━━━━━━━
SECTION 4 — BUILD, FLASH, AND FIRST POWER-ON
━━━━━━━━━━━━━━━━━━━━━━━━━━━━━━━━━━━━━━━━━━━━━━━━━━━━━━━━━━━━━━━━━━━━━━━━━━━━━━

--- 4.1  Build Errors (11 Errors — All Fixed) ---

  ERROR 1-3: 'Contractor_GPIO_Port' undeclared (3 locations in motor.c)
    Root cause: CubeMX generated the GPIO label as "Contactor_" but our
                code used "Contractor_" (typo — letters transposed).
    Fix: Renamed all 3 occurrences in motor.c:
           Motor_Init()      → Contactor_GPIO_Port / Contactor_Pin
           Motor_Energize()  → Contactor_GPIO_Port / Contactor_Pin
           Motor_Deenergize()→ Contactor_GPIO_Port / Contactor_Pin

  ERROR 4: 'huart1' undeclared in stm32f4xx_it.c
    Root cause: Missing extern declaration in interrupt file.
    Fix: Added in External Variables section of stm32f4xx_it.c:
           extern UART_HandleTypeDef huart1;

  ERROR 5: 'htim3' undeclared in stm32f4xx_it.c
    Root cause: Same — missing extern.
    Fix: Added extern TIM_HandleTypeDef htim3; in stm32f4xx_it.c.

  (Remaining errors were cascading from the above root causes.)

  Result: Clean build — 0 errors, 0 warnings after fixes.

--- 4.2  Flashing ---

  User connected ST-Link V2 debugger to Black Pill SWD pins.
  Flashed via STM32CubeProgrammer / ST-Link interface.
  (Note: USB-C on Black Pill requires BOOT0 held HIGH while powering —
   only needed for DFU/USB bootloader, not required when using ST-Link.)

━━━━━━━━━━━━━━━━━━━━━━━━━━━━━━━━━━━━━━━━━━━━━━━━━━━━━━━━━━━━━━━━━━━━━━━━━━━━━━
SECTION 5 — HARDWARE DEBUGGING (3 Issues Resolved)
━━━━━━━━━━━━━━━━━━━━━━━━━━━━━━━━━━━━━━━━━━━━━━━━━━━━━━━━━━━━━━━━━━━━━━━━━━━━━━

━━━━━━━━━━━━━━━━━━━━━━━━━━━━━━━━━━━━━━━━━━━━━━━━━━━━━━━━━━━━━━━━━━━━━━━━━━━━━━
  BUG #1 — Contactor Not Clicking on Boot
━━━━━━━━━━━━━━━━━━━━━━━━━━━━━━━━━━━━━━━━━━━━━━━━━━━━━━━━━━━━━━━━━━━━━━━━━━━━━━

  Symptom: After first flash, contactor did not click. On BBB, the contactor
           clicked automatically on boot (confirming system ready). On STM32
           the only contactor trigger was the SWD rising-edge detection.

  Root cause: Original STM32 code only energised on SWD toggle (rising edge
              detect). No auto-energise on startup.

  Fix: Added Motor_Energize() call in USER CODE BEGIN 2 of main.c,
       immediately after Motor_Init() / IBUS_Init():

         Motor_Energize();
         last_contactor_ts = TIM5->CNT;  // start debounce from this moment

  Result: Contactor clicks ~500 ms after boot — same behaviour as BBB.
          Confirmed working by user.

━━━━━━━━━━━━━━━━━━━━━━━━━━━━━━━━━━━━━━━━━━━━━━━━━━━━━━━━━━━━━━━━━━━━━━━━━━━━━━
  BUG #2 — iBUS Not Receiving (FlySky RC Unresponsive)
━━━━━━━━━━━━━━━━━━━━━━━━━━━━━━━━━━━━━━━━━━━━━━━━━━━━━━━━━━━━━━━━━━━━━━━━━━━━━━

  Symptom: Contactor clicked (boot confirmed), FlySky bound to receiver,
           but no stick movement / switch commands had any effect.

  --- Sub-bug A: NVIC not enabled for USART1 ---

    Root cause: CubeMX does not automatically add NVIC enable calls in
                HAL_UART_MspInit() unless "NVIC" is explicitly configured
                in the CubeMX NVIC panel. It was not set.
                Result: USART1 interrupts never fired.

    Fix: Manually added to stm32f4xx_hal_msp.c in USER CODE section
         inside HAL_UART_MspInit():

           HAL_NVIC_SetPriority(USART1_IRQn, 5, 0);
           HAL_NVIC_EnableIRQ(USART1_IRQn);

  --- Sub-bug B: DMA not configured — HAL_UART_Receive_DMA() silently failed ---

    Root cause: ibus.c called HAL_UART_Receive_DMA() but DMA2 Stream 2
                was never enabled in CubeMX. The huart1.hdmarx pointer was
                NULL. The call returned HAL_ERROR silently — no assertion,
                no crash — just no data ever arrived in the buffer.

    Fix: User added DMA to CubeMX configuration:
           DMA2, Stream 2, Channel 4, Direction = Peripheral→Memory,
           Mode = Normal, Data Width = Byte/Byte.
         CubeMX regenerated MX_DMA_Init() and added it BEFORE MX_I2C1_Init()
         in main.c (correct order — DMA must init before peripherals that use it).

  --- Sub-bug C: Duplicate USART1_IRQHandler after CubeMX regeneration ---

    Root cause: After CubeMX regenerated stm32f4xx_it.c, it added its own
                USART1_IRQHandler(). Our previous USER CODE still had a
                duplicate handler inside USER CODE BEGIN 1. Two handlers
                for same IRQ = linker error / undefined behaviour.

    Fix: Removed our duplicate handler from USER CODE BEGIN 1.
         Moved IDLE detection into the CubeMX-generated handler using
         USER CODE sections:

           /* In USART1_IRQHandler, USER CODE BEGIN USART1_IRQn 0: */
           if (__HAL_UART_GET_FLAG(&huart1, UART_FLAG_IDLE))
               IBUS_IdleCallback();

  --- Sub-bug D: IDLE flag clearing (STM32F4 specific) ---

    On STM32F4, IDLE flag is cleared by reading SR then DR (not by a
    simple macro). The correct macro is __HAL_UART_CLEAR_IDLEFLAG()
    which performs the SR→DR read sequence.
    Confirmed this was used correctly in IBUS_IdleCallback().

  --- Physical Connection Note ---

    iBUS receiver signal line runs at 5 V logic level.
    BBB was protected by a voltage divider (5V → 3.3V) on the PCB.
    STM32 PA10 is 5V-tolerant on STM32F4, so the same PCB voltage divider
    is compatible. User confirmed physical connection using jumper wires
    from PCB's P9_19 and P9_20 pads to STM32 PB6 and PB7.

  Result: After all four sub-bugs fixed, iBUS reception working.
          SWD arm/disarm confirmed working (contactor clicks).

━━━━━━━━━━━━━━━━━━━━━━━━━━━━━━━━━━━━━━━━━━━━━━━━━━━━━━━━━━━━━━━━━━━━━━━━━━━━━━
  BUG #3 — Motor Throttle Not Responding (Stick Movement No Effect)
━━━━━━━━━━━━━━━━━━━━━━━━━━━━━━━━━━━━━━━━━━━━━━━━━━━━━━━━━━━━━━━━━━━━━━━━━━━━━━

  Symptom: iBUS working (SWD contactor toggle confirmed), but moving throttle
           / steering sticks caused no voltage change on DAC output pins.
           Multimeter on MCP4725 Vout: stuck at 0 V regardless of stick pos.
           I2C SDA (PB7) and SCL (PB6): both read 3.2 V (pull-ups working).

  --- Sub-bug A: Missing MCP4725 command byte ---

    Root cause: Original _WriteDac() sent only 2 bytes (upper nibble, lower
                nibble). The MCP4725 requires a 3-byte transaction:
                  Byte 0: 0x40 (Write DAC Register, no EEPROM)
                  Byte 1: D[11:4]
                  Byte 2: D[3:0] << 4
                Without the command byte, the chip interpreted the data bytes
                as a command (0x00 = fast write to DAC+EEPROM with value 0),
                so it output 0 V consistently regardless of what we sent.

    Reference: BBB used Python smbus2:
                 write_i2c_block_data(addr, 0x40, [upper, lower])
               Which sends exactly 3 bytes: command=0x40, then 2 data bytes.

    Fix: Rewrote _WriteDac() in motor.c:

           static void _WriteDac(uint8_t addr, uint16_t value)
           {
               if (value > DAC_MAX) value = DAC_MAX;
               uint8_t buf[3];
               buf[0] = 0x40U;
               buf[1] = (uint8_t)((value >> 4) & 0xFFU);
               buf[2] = (uint8_t)((value << 4) & 0xFFU);
               HAL_I2C_Master_Transmit(&hi2c1, (uint16_t)(addr << 1),
                                       buf, 3U, 50U);
           }

  --- Sub-bug B: I2C speed incompatible with 4.7 kΩ pull-up resistors ---

    Root cause: I2C1 was configured at 400 kHz (Fast Mode).
                Fast Mode requires signal rise time ≤ 300 ns.
                PCB pull-up resistors: 4.7 kΩ to 3.3 V.
                Bus capacitance: ~100 pF (typical PCB trace + chip input).
                Rise time = 0.8473 × R × C ≈ 0.8473 × 4700 × 100e-12 ≈ 398 ns
                            (or simple RC: τ = 470 ns → 63% in 470 ns)
                This exceeds the 300 ns limit → I2C framing errors → no ACK.

    Fix: Changed I2C1 clock from 400 kHz to 100 kHz (Standard Mode).
         At 100 kHz, rise time limit is 1000 ns — well within 470 ns actual.
         Changed in main.c MX_I2C1_Init():

           hi2c1.Init.ClockSpeed = 100000;

         Also increased _WriteDac() HAL timeout from 10 ms to 50 ms.

    IMPORTANT NOTE: If CubeMX is ever used to regenerate code, the I2C1
                    must be set to "Standard Mode 100 kHz" in CubeMX,
                    otherwise regeneration will overwrite this back to 400 kHz.

  Status: Fix applied (100 kHz I2C + correct 3-byte DAC command).
          Rebuild and flash pending at end of Session 2.
          Expected result: multimeter on DAC Vout should now show voltage
          changing (0 V → ~3.3 V range) as throttle stick is moved.

━━━━━━━━━━━━━━━━━━━━━━━━━━━━━━━━━━━━━━━━━━━━━━━━━━━━━━━━━━━━━━━━━━━━━━━━━━━━━━
  BUG #4 — Reverse Does Nothing (Stays Forward); Left Steering Does Nothing
  (Stays Right) — Found and Fixed 2026-07-30
━━━━━━━━━━━━━━━━━━━━━━━━━━━━━━━━━━━━━━━━━━━━━━━━━━━━━━━━━━━━━━━━━━━━━━━━━━━━━━

  Symptom: Forward throttle and right steering worked correctly. Reverse
           throttle had no effect (motors kept driving forward). Left
           steering had no effect (rover kept turning right regardless of
           stick position).

  Root cause: Core/Src/ibus.c, _ToFloat(). IBUS_VAL_MIN/MID/MAX are #define'd
              in config.h with a U suffix (unsigned int). The line

                norm = (float)(raw - IBUS_VAL_MID) / ...

              forces `raw - IBUS_VAL_MID` into UNSIGNED arithmetic whenever
              raw < IBUS_VAL_MID (i.e. any stick position below center —
              reverse throttle or left steering). Example: raw=1000,
              IBUS_VAL_MID=1500 → 1000u - 1500u does not give -500, it wraps
              to 4294966796u. Cast to float, that's ~+8.59 million instead
              of -1.0.

              Downstream, this huge positive garbage value:
                - As Yn: going_fwd = (Yn > 0.0f) evaluates true regardless
                  of intent → robot always computed as driving forward.
                - As Xn: the steering formula treats it as a large positive
                  (right-side) command → robot always steered as if turning
                  right.

              Values with raw >= IBUS_VAL_MID (forward throttle, right
              steering) never hit the wraparound, which is why those
              directions worked and the negative side silently didn't.

              This bug has no equivalent in the original BBB Python
              (drivers/flysky_receiver.py `_to_float`) — Python integers
              are arbitrary-precision and signed, so `raw - IBUS_MID` just
              works. It was introduced purely by the C port picking up the
              `U` suffix on the config constants.

  Fix: Cast to a signed type before subtracting, in Core/Src/ibus.c:

         int32_t diff = (int32_t)raw - (int32_t)IBUS_VAL_MID;
         norm = (float)diff / (float)(IBUS_VAL_MID - IBUS_VAL_MIN);   /* or MAX-MID */

       Scanned the rest of Core/Src for the same "(unsigned constant) -
       (unsigned constant)" pattern — no other occurrence found.

  Status: Fixed in source. Rebuilt and flashed 2026-07-30 along with Bug #5
          below (both found in the same test session).

━━━━━━━━━━━━━━━━━━━━━━━━━━━━━━━━━━━━━━━━━━━━━━━━━━━━━━━━━━━━━━━━━━━━━━━━━━━━━━
  BUG #5 — Total Freeze After Rebuild (Only Boot-Time Contactor Click Works,
  Nothing Else Responds) — Found and Fixed 2026-07-30
━━━━━━━━━━━━━━━━━━━━━━━━━━━━━━━━━━━━━━━━━━━━━━━━━━━━━━━━━━━━━━━━━━━━━━━━━━━━━━

  Symptom: After rebuilding/flashing the Bug #4 fix (which also carried the
           earlier TIM3-NVIC change from the same session), the contactor
           still clicked once at boot, but nothing else worked at all — no
           forward, no reverse, no left, no right, and (implicitly) no live
           SWD arm/disarm either. This is a regression introduced by THIS
           session's own earlier TIM3 NVIC fix, not by Bug #4.

  Root cause: HAL_TIM_Encoder_Start_IT(&htim3, TIM_CHANNEL_ALL) — called
              from Encoder_Init() — does NOT enable TIM3's Update interrupt.
              Checked the HAL source directly
              (Drivers/STM32F4xx_HAL_Driver/Src/stm32f4xx_hal_tim.c,
              HAL_TIM_Encoder_Start_IT, TIM_CHANNEL_ALL branch): it enables
              TIM_IT_CC1 and TIM_IT_CC2 — the capture-compare interrupts
              that fire on every quadrature edge — not TIM_IT_UPDATE.

              TIM3_IRQHandler (added earlier this session) only checked and
              cleared the UPDATE flag:

                if (__HAL_TIM_GET_FLAG(&htim3, TIM_FLAG_UPDATE) && ...)
                    __HAL_TIM_CLEAR_IT(&htim3, TIM_IT_UPDATE);

              So the first time the right wheel turned and generated a
              CC1/CC2 edge: TIM3_IRQn fired (now unmasked at NVIC by this
              session's earlier fix) → the ISR's UPDATE check was false →
              the CC1/CC2 flag that caused entry was never cleared → the
              IRQ re-fired the instant the ISR returned → infinite interrupt
              storm → main loop starved of CPU forever. The contactor had
              already clicked (in Motor_Energize(), called before the first
              wheel ever turns), so it looked "engaged" while everything
              else silently died the moment the wheels first moved.

              Before this session, TIM3_IRQn was masked at the NVIC, so the
              CC1/CC2 flags set harmlessly and nothing ever serviced them —
              which is also why the original 16-bit-overflow problem (the
              thing the NVIC fix was trying to solve) never caused a crash,
              just silently-wrong RPM after ~82s of continuous rotation.

  Fix: Removed the interrupt-driven approach entirely and switched TIM3
       overflow tracking to polling, since Encoder_Update() already runs
       every 20 Hz tick and a 16-bit counter at max wheel speed doesn't
       wrap for ~82s (huge margin vs. a 50ms poll interval):
         - encoder.c: Encoder_Init() now calls HAL_TIM_Encoder_Start()
           (non-IT) for TIM3, same as TIM2.
         - encoder.c: Encoder_Update() now polls and clears
           __HAL_TIM_GET_FLAG(&htim3, TIM_FLAG_UPDATE) once per call and
           invokes the (now-static, internal) overflow handler directly —
           no ISR involved.
         - stm32f4xx_it.c: removed the TIM3_IRQHandler USER CODE block
           entirely (left a comment explaining why, to stop this from being
           reintroduced the same way). TIM3's vector now falls through to
           the default weak handler, which is correct since NVIC is masked.
         - stm32f4xx_hal_msp.c: removed the TIM3_IRQn NVIC enable from
           HAL_TIM_Encoder_MspInit() (left a comment pointing at the polling
           approach instead).
         - encoder.h: removed Encoder_TIM3_OvfCallback() from the public
           API — it's internal-only now (renamed _TIM3_OvfHandler, static).

  Lesson: HAL_TIM_Encoder_Start_IT() enables CC1/CC2 (edge) interrupts, NOT
          the Update interrupt, regardless of channel argument. If you need
          Update/overflow interrupts alongside encoder mode, either handle
          CC1/CC2 in the ISR too (e.g. by calling HAL_TIM_IRQHandler(), which
          services all three), or don't use interrupts for the overflow
          case at all — poll it from wherever you already read the counter
          on a fixed schedule, as done here.

  Status: Fixed and CONFIRMED — rebuilt/flashed 2026-07-30, freeze is gone
          (main loop alive: SWD-driven contactor and brake-release both
          respond to commands correctly now). Still need the >90s
          continuous-rotation soak test to be fully confident no
          encoder-related freeze remains.

━━━━━━━━━━━━━━━━━━━━━━━━━━━━━━━━━━━━━━━━━━━━━━━━━━━━━━━━━━━━━━━━━━━━━━━━━━━━━━
  OPEN INVESTIGATION — No Wheel Movement At All, Despite Brake Releasing
  Correctly (Opened 2026-07-30, root cause not yet confirmed)
━━━━━━━━━━━━━━━━━━━━━━━━━━━━━━━━━━━━━━━━━━━━━━━━━━━━━━━━━━━━━━━━━━━━━━━━━━━━━━

  Symptom: After the Bug #5 fix, tested again: brake GPIOs release correctly
           on command (confirmed with multimeter — main loop and motor
           state machine are alive and reaching Motor_SetSpeeds() /
           Motor_BrakeThenReverse()), but no forward/reverse/left/right
           motion happens at all.

  Checked and ruled out:
    - I2C1 clock speed: confirmed 100 kHz Standard Mode in BOTH Rover.ioc
      (I2C1.I2C_Mode=I2C_Standard) and the generated main.c
      (hi2c1.Init.ClockSpeed = 100000) — this was NOT reverted to 400 kHz.
    - Re-read ibus.c, pipeline.c, kinematics.c, motor.c, main.c end-to-end
      against the intended logic — no further sign/logic bugs found; the
      code path from RC input to _WriteDac() call looks correct.
    - Note: the original Bug #3 fix (3-byte DAC command + 100kHz I2C) was
      applied in Session 2 but NEVER actually verified on hardware before
      now — testing was blocked first by Bug #4, then Bug #5. This may be
      the first real hardware test of that fix, so it's possible the DAC
      path has an issue that predates this session entirely (wiring, DAC
      power, address strapping, level shifter) rather than being a new
      regression.

  Gap found: motor.c _WriteDac() discarded HAL_I2C_Master_Transmit()'s
             return status entirely. If the DAC isn't ACKing (bad wiring,
             no power to the MCP4725, wrong address), the firmware has no
             way to detect or report it — it just silently keeps outputting
             0V forever, which matches the symptom.

  Added (not a fix — a diagnostic): PC13 (onboard LED on this Black Pill,
  active-LOW, confirmed unused elsewhere in the project) now latches ON the
  first time either DAC's I2C write fails to complete, and stays on until
  the next Motor_Init(). Core/Src/motor.c: _DiagLedInit() (called from
  Motor_Init()) and _DiagLedLatchFail() (called from _WriteDac() on
  non-HAL_OK status).

  Next steps (needs the physical hardware in front of the user):
    [ ] Rebuild/flash, command movement, check whether the onboard LED
        lights up:
          - LED ON  → I2C write to a DAC is failing at the hardware level.
            Check: DAC power supply, SDA/SCL wiring continuity to PB6/PB7,
            MCP4725 address-select pin strapping (0x60 vs 0x61), and
            confirm both DACs are actually present with a simple
            HAL_I2C_IsDeviceReady() bus scan if the LED points this way.
          - LED OFF → I2C writes are succeeding (DAC is ACKing), so the
            problem is downstream of the DAC — check DAC Vout directly
            with a multimeter while commanding motion (should move between
            ~0V and ~3.3V), then check the level-shifter board and motor
            controller throttle input if Vout does change but the wheels
            still don't move.

━━━━━━━━━━━━━━━━━━━━━━━━━━━━━━━━━━━━━━━━━━━━━━━━━━━━━━━━━━━━━━━━━━━━━━━━━━━━━━
  ROLLBACK — 2026-07-30, same day as Bug #5 / Open Investigation above
━━━━━━━━━━━━━━━━━━━━━━━━━━━━━━━━━━━━━━━━━━━━━━━━━━━━━━━━━━━━━━━━━━━━━━━━━━━━━━

  After the Open Investigation entry above (no wheel movement at all despite
  brake releasing), the user pointed out — correctly — that the previous,
  unmodified files had ONLY the reverse/left problem (Bug #4) and otherwise
  drove fine, and that this session's changes made it categorically worse
  (zero directions working instead of two). The mistake: several speculative
  fixes (TIM3 NVIC → Bug #5 → polling revert, the RC-safe blocking-delay
  logic, the diagnostic LED) were bundled into one rebuild/flash/test cycle
  instead of being tested one at a time. When the combined result regressed,
  there was no way to isolate which change was responsible.

  Action taken: reverted Core/Src/motor.c, Core/Src/encoder.c,
  Core/Inc/encoder.h, Core/Src/stm32f4xx_it.c, Core/Src/stm32f4xx_hal_msp.c,
  and Core/Inc/ibus.h to their exact pre-Session-3 state. The ONE change kept
  is the Bug #4 fix in ibus.c _ToFloat() (the signed-cast subtraction) —
  reasoned through carefully, mechanically simple (a pure function, no
  interrupts/timing/state involved), and independently verifiable by
  inspection, so it's the one change actually safe to isolate and test.

  This means Bug #5 (TIM3 interrupt storm) and the RC-safe blocking-delay
  safety net are BACK — i.e. TIM3 Start_IT + masked NVIC is back (harmless,
  matches the original working baseline), and Motor_SetSpeeds() /
  Motor_BrakeThenReverse() are back to plain unconditional _DelayUs() with
  no RC-abort logic. Both write-ups below are kept for the reasoning (the
  interrupt-storm mechanism and the DAC-error-checking gap are still real
  and worth revisiting), but neither fix is currently in the code — do not
  assume they are.

  Going forward: one change per rebuild/flash/test cycle. Confirm each
  fix in isolation before layering the next one on top.

━━━━━━━━━━━━━━━━━━━━━━━━━━━━━━━━━━━━━━━━━━━━━━━━━━━━━━━━━━━━━━━━━━━━━━━━━━━━━━
  EXPERIMENT — No Movement After Cold Power-Up, Works Fine After Manual
  Reset (Opened 2026-08-??, not yet verified on hardware)
━━━━━━━━━━━━━━━━━━━━━━━━━━━━━━━━━━━━━━━━━━━━━━━━━━━━━━━━━━━━━━━━━━━━━━━━━━━━━━

  Symptom: After powering the whole system from cold, contactor clicks
           audibly and SWD-triggered arm/disarm via the transmitter works
           (both confirmed) — but no forward/reverse/any movement happens.
           Pressing the STM32's own RESET button (not a full power cycle)
           immediately fixes it; everything then works normally for the
           rest of that session.

  Hypothesis: contactor (GPIO) and iBUS/SWD (UART) both work fine on cold
              boot, and both are entirely independent of I2C — the only
              thing broken is anything that depends on writing the DAC
              over I2C. That narrows this specifically to I2C, not a
              general MCU boot problem.

              The STM32 itself boots and starts executing within low
              single-digit milliseconds of power being applied. The rest
              of the board (DAC supply rail, whatever regulator feeds the
              MCP4725s) likely has a slower power-up ramp. Motor_Init()
              runs almost immediately after boot and previously attempted
              its first _WriteDac() calls before that supply had
              necessarily stabilised. An I2C transaction attempted against
              a not-yet-powered (or only-just-powering) slave can leave
              the bus or the STM32's own I2C1 peripheral state wedged, so
              every LATER I2C transaction keeps failing too — even once
              the DAC is fully powered — because the bus/peripheral state
              is stuck, not because the DAC isn't ready anymore.

              A manual reset re-runs the exact same init sequence, but by
              the time a human presses the button, the DAC rail has long
              since stabilised (seconds have passed since cold power-on),
              so the same sequence that failed at cold boot succeeds
              cleanly on reset. This matches the reported behaviour
              exactly (reset fixes it, power-up alone doesn't).

  Fix (single isolated change, per the one-change-at-a-time rule):
       Core/Src/motor.c — added _WaitForDacsReady(), called at the very
       start of Motor_Init(), BEFORE the first _WriteDac() calls. Polls
       HAL_I2C_IsDeviceReady() for both DAC_LEFT_ADDR and DAC_RIGHT_ADDR
       every 50ms, capped at a hard 2s timeout (falls through and
       proceeds anyway if the DAC genuinely never responds — no worse
       than current behaviour in a true hardware-fault case). Confirmed
       HAL_I2C_IsDeviceReady() itself is internally bounded (uses
       I2C_WaitOnFlagUntilTimeout for the BUSY flag, returns HAL_BUSY
       rather than hanging) — verified directly in
       Drivers/STM32F4xx_HAL_Driver/Src/stm32f4xx_hal_i2c.c.

       Note: TIM5 is not started until Encoder_Init(), which runs AFTER
       Motor_Init() in main.c. Since _WaitForDacsReady() needs TIM5 for
       its own polling delay, it calls HAL_TIM_Base_Start(&htim5) itself
       first — Encoder_Init() starting it again afterward is harmless
       (idempotent).

  Caveat / what this does NOT rule out: HAL_I2C_IsDeviceReady() itself
  issues a real I2C START condition and address probe — it's not a passive
  check. If the actual failure mode is the DAC ACTIVELY holding SDA low
  while partially (not fully) powered — rather than simply being absent/
  unpowered and giving a clean no-ACK — then the very first readiness
  probe could wedge the bus the same way a raw write would, and this fix
  wouldn't help. This is considered less likely (a fully unpowered device
  typically gives a clean timeout, not a wedge — wedging usually needs an
  actively-driving device that gets interrupted mid-transaction), but
  isn't proven either way without hardware access. If this fix does NOT
  resolve the symptom, the next thing to try is an active I2C bus-recovery
  routine (manually clock SCL as GPIO for up to 9 pulses to unstick a
  slave before HAL_I2C_Init() runs) — not implemented, only try this if
  the current fix fails, and still one change at a time.

  Status: TESTED, DID NOT FIX IT. User rebuilt, flashed, power-cycled the
          whole system from cold several times — cold-boot no-movement
          issue still present. This confirms the caveat above: waiting for
          an ACK via HAL_I2C_IsDeviceReady() is not sufficient — the probe
          itself is a real I2C transaction and can apparently wedge things
          the same way a raw write would. _WaitForDacsReady() is left in
          place (harmless, near-zero cost once the bus is actually healthy)
          but is NOT the fix. See "Forced Software Reset" entry below for
          the approach used instead.

━━━━━━━━━━━━━━━━━━━━━━━━━━━━━━━━━━━━━━━━━━━━━━━━━━━━━━━━━━━━━━━━━━━━━━━━━━━━━━
  FIX — Forced Software Self-Reset on Cold Boot (opened same session as
  above, not yet tested)
━━━━━━━━━━━━━━━━━━━━━━━━━━━━━━━━━━━━━━━━━━━━━━━━━━━━━━━━━━━━━━━━━━━━━━━━━━━━━━

  Since waiting-and-probing didn't resolve the cold-boot I2C issue, and a
  manual reset reliably does, the user asked to automate exactly that:
  wait a few seconds after power-up, then force a reset in software so the
  full init sequence re-runs once the DAC rail has had time to settle —
  same effect as pressing the physical reset button, done automatically.

  Danger avoided: a naive "always wait N seconds then reset" would reset
  in an infinite loop, since triggering NVIC_SystemReset() itself causes
  another boot that would see the same "wait then reset" code and repeat
  forever. Fixed by checking RCC->CSR's reset-cause flags, which persist
  across a reset until explicitly cleared:
    - RCC_FLAG_PORRST / RCC_FLAG_BORRST → genuine power-on/brown-out reset
      (a real cold boot) → run the wait-then-reset logic.
    - RCC_FLAG_SFTRST → the reset was caused by our own NVIC_SystemReset()
      call → skip the block entirely, proceed straight to normal init.
    - RCC_FLAG_PINRST (manual reset button) → also skipped, so a user
      pressing reset later in a session doesn't re-trigger this.

  Implementation — Core/Src/main.c, in the USER CODE Init section, right
  after HAL_Init() and BEFORE SystemClock_Config() or any peripheral init
  (so nothing touches I2C/GPIO/etc. during the wait):

    if (__HAL_RCC_GET_FLAG(RCC_FLAG_PORRST) || __HAL_RCC_GET_FLAG(RCC_FLAG_BORRST))
    {
        __HAL_RCC_CLEAR_RESET_FLAGS();
        HAL_Delay(3000);
        NVIC_SystemReset();   /* never returns */
    }
    __HAL_RCC_CLEAR_RESET_FLAGS();

  HAL_Delay() works correctly here even though this runs before
  SystemClock_Config() — HAL_Init() already configured SysTick against
  whatever clock is active at that point (default post-reset HSI), and
  SystemClock_Config()'s HAL_RCC_ClockConfig() call re-calibrates SysTick
  for the new 100MHz clock afterward on the "real" boot — the two don't
  conflict since they happen in separate boot cycles.

  Known behavioural change: every cold power-up now takes ~3s longer
  before the contactor click ("system ready" indicator) is heard — click
  now happens at roughly T+3s+(normal boot time)+500ms settle, not
  immediately. This is expected; the delay is the whole point. During the
  3s wait itself nothing is armed and no peripherals besides the default
  clock are touched, so there's no new safety exposure in that window —
  the DAC path wasn't working during an equivalent window before this fix
  either.

  3000ms is the user's empirically-confirmed manual-reset wait; may need
  tuning (shorter/longer) based on further cold-boot testing.

  Status: TESTED, DID NOT FIX IT. Contactor confirmed clicking ~3s later
          as expected (proves the delay/reset logic itself ran correctly),
          but the vehicle still would not move without a manual reset
          button press. SUPERSEDED — see "FIX — I2C1 Bus-Clear Recovery"
          below for why (a reset, software or hardware, cannot fix this
          class of problem) and what replaced it. This code has been
          REMOVED from main.c, not left in place.

━━━━━━━━━━━━━━━━━━━━━━━━━━━━━━━━━━━━━━━━━━━━━━━━━━━━━━━━━━━━━━━━━━━━━━━━━━━━━━
  FIX — I2C1 Bus-Clear Recovery on Boot (replaces the forced-reset attempt
  above; researched via web search per user request)
━━━━━━━━━━━━━━━━━━━━━━━━━━━━━━━━━━━━━━━━━━━━━━━━━━━━━━━━━━━━━━━━━━━━━━━━━━━━━━

  User pushed back: contactor now clicks ~3s late as expected (confirming
  the reset logic itself was running), but movement still required a
  manual reset press. Asked to research the actual reason.

  Root cause (confirmed via web search, not just internal reasoning this
  time): a reset — hardware NRST OR software NVIC_SystemReset() — ONLY
  clears the STM32's own internal peripheral/register state. It has NO
  effect on an external I2C slave that is actively holding SDA (or SCL)
  low. If the MCP4725 DAC was mid-transaction when its supply was still
  ramping up during cold boot, it can freeze holding SDA low, waiting for
  clock pulses that never arrive. When I2C1 re-initialises after ANY kind
  of reset, it immediately sees SDA held low and reports BUSY again —
  identical symptom to what we saw. This is a well-documented, independently
  confirmed STM32 I2C failure mode:
    - ST Community: "Can't reset I2C in STM32F407 to release I2C lines"
      https://community.st.com/t5/stm32-mcus-products/can-t-reset-i2c-in-stm32f407-to-release-i2c-lines/td-p/463531
      — user found HAL_I2C_DeInit()/re-init and even the SWRST bit did NOT
      release the lines; the fix that worked was: reconfigure SCL/SDA as
      GPIO outputs, generate 9 manual clock pulses, THEN reset/reinit I2C.
    - "Resolving STM32F4xx I2C Stuck Busy After MCU Software Reset"
      https://www.zyma.me/post/stm32f4-i2c-busy-after-software-reset/
      — STM32F4-specific, same symptom (stuck BUSY surviving a software
      reset), same fix: bit-bang ~10 SCL pulses with SDA held high (NACK),
      then leave SCL high (idle) before re-initialising I2C as a peripheral.
    - General I2C-bus spec background: the BUSY flag reflects live GPIO
      bus state, not just internal register state, so an internal reset
      can't clear it while an external device is still physically driving
      a line low.

  Fix — Core/Src/main.c:
    - Added _I2C1_BusRecovery() (USER CODE 0, before main()): configures
      PB6/PB7 as plain open-drain GPIO (not I2C yet), releases SDA (lets
      the 4.7k pull-up bring it high), clocks SCL 9 times, then generates
      a manual STOP condition (SDA low->high while SCL high) to leave the
      bus cleanly idle. Pure GPIO bit-banging — the I2C1 peripheral isn't
      touched at all here.
    - Called from USER CODE BEGIN Init, right after HAL_Init() and BEFORE
      SystemClock_Config()/MX_GPIO_Init()/MX_I2C1_Init() — critical
      ordering, since MX_I2C1_Init() (via HAL_I2C_MspInit()) reconfigures
      PB6/PB7 into I2C alternate-function mode, which would undo the raw
      GPIO manipulation if this ran afterward.
    - REMOVED the 3s-delay-then-NVIC_SystemReset() block entirely — it's
      now confirmed not to be the actual fix, so keeping it would just add
      needless boot delay for no benefit.
    - Runs unconditionally on every boot (no RCC_FLAG_PORRST/BORRST check
      needed this time) — it's fast (well under a millisecond) and
      harmless on an already-idle bus, since a healthy slave ignores clock
      edges with no preceding START condition.
    - _WaitForDacsReady() in motor.c (Motor_Init(), polls
      HAL_I2C_IsDeviceReady()) is LEFT IN PLACE as a complementary second
      layer — it addresses a different failure mode (DAC simply not
      powered up YET, not actively stuck) that bus recovery alone doesn't
      cover.

  Status: TESTED, DID NOT FIX IT ALONE. User rebuilt/flashed/power-cycled
          from cold — movement still not working. Bus-clear recovery by
          itself was insufficient. User also reported reverse now only
          engages with a slow stick pull, not a sustained hold — same
          "needs many small attempts, fails on one clean attempt" pattern
          as before the DAC ramp fix, despite the ramp code being
          unchanged since it was confirmed working. Working theory: this
          is the SAME underlying I2C reliability problem, not a ramp
          regression — an intermittently-bad bus would make many small
          writes (slow pull) look reliable while a single/few writes (fast
          push, or a fresh cold-boot write) look broken, without any
          change to the ramp logic itself.

          User asked to bring the 3s cold-boot delay back (kept scoped to
          RCC_FLAG_PORRST/BORRST only, per the earlier design — a later
          manual reset press doesn't also incur it) — this time run
          BEFORE _I2C1_BusRecovery(), not instead of it, and with no
          self-reset (confirmed not to help, not worth the extra boot
          time). Rationale: recovery needs the DAC to be properly powered
          to respond predictably to the SCL clock-out; if the bus-recovery
          bit-bang ran while the DAC's own supply was still mid-ramp, it
          may not have been able to do its job correctly. Giving the rail
          3s to settle FIRST, then running recovery on a now-stable
          device, is a reasonable combination of both mechanisms rather
          than either alone.

          Deliberately did NOT touch motor.c / the ramp logic in this
          change, per the working theory above — if I2C becomes reliable
          from this fix, the reverse-hold issue should resolve as a
          byproduct without any separate change needed. If it's still
          flaky after this, THAT would be real evidence the ramp logic
          itself needs attention, separately.

  Status: TESTED, DID NOT FIX IT. Delay + bus-recovery combined still did
          not restore cold-boot movement. SUPERSEDED — see "FIX — Zero
          Throttle Confirmed Before Contactor Closes" below, which
          re-diagnoses the whole problem.

━━━━━━━━━━━━━━━━━━━━━━━━━━━━━━━━━━━━━━━━━━━━━━━━━━━━━━━━━━━━━━━━━━━━━━━━━━━━━━
  FIX — Zero Throttle Confirmed Before Contactor Closes (re-diagnosis
  after four failed I2C-focused attempts)
━━━━━━━━━━━━━━━━━━━━━━━━━━━━━━━━━━━━━━━━━━━━━━━━━━━━━━━━━━━━━━━━━━━━━━━━━━━━━━

  Context: four consecutive fix attempts all failed (DAC-ready polling,
  forced software self-reset, boot-time bus recovery, delay + recovery
  combined). All four shared one assumption: that the fault was purely an
  I2C bus/timing problem. The key evidence that DISPROVES that assumption
  had been overlooked — the 3s-delay-then-reset attempt produced a
  correctly-delayed contactor click (so the delay definitely ran, and the
  DAC rail had a full 3 seconds to stabilise) and STILL no movement. If
  this were only "DAC not powered up in time," that attempt should have
  worked. It didn't. So the I2C-timing story is at best incomplete.

  New root-cause hypothesis (fits EVERY observation, including the ones
  the previous theories could not explain):

    The BLDC controllers latch a refuse-to-run fault at the moment the
    contactor closes, and only a contactor power-cycle clears it.

    E-scooter BLDC controllers near-universally self-check "is throttle at
    zero?" at their own power-up, latching a fault if it isn't (standard
    anti-runaway safety). The contactor is what feeds them power — so the
    instant the contactor closes IS their power-up moment.

    - COLD BOOT: the MCP4725 powers up outputting whatever is in its
      internal EEPROM, which is not necessarily 0 V. Motor_Init() attempts
      to write 0, but if that write fails (bus not yet healthy), the DAC
      is STILL sitting at that non-zero voltage when Motor_Energize()
      closes the contactor ~immediately after. Controllers power up, see
      non-zero throttle, latch fault. From that moment no amount of
      correct DAC writes will move the wheels — the controllers are done
      until power-cycled.

    - AFTER PRESSING RESET: the DAC is NOT power-cycled by an STM32 reset
      — it stays powered and keeps holding the 0 V written during the
      previous session. Motor_Init() opens the contactor, Motor_Energize()
      re-closes it, and the controllers power up seeing a clean, genuine
      0 V → no fault latched → everything works. THIS is why the reset
      button "fixes" it, and why it looked like an MCU-side problem when
      it never was.

  This also explains why the immediately-preceding fix failed: that
  revision called _I2C1_Recover() from Motor_Energize() but placed it
  AFTER the contactor GPIO was already set high and after the 500 ms
  settle. The controllers had already latched their fault half a second
  before the recovery code ever executed. Right idea, fatally wrong place.

  Fix — Core/Src/motor.c:
    - _WriteDacChecked(): new variant of _WriteDac() that RETURNS the HAL
      status instead of discarding it (the long-standing gap first noted
      back in the "Open Investigation" entry, finally acted on).
      _WriteDac() is kept as a fire-and-forget wrapper for the normal
      driving path, where a single failed mid-manoeuvre write isn't
      independently actionable.
    - _EnsureDacsZeroed(): writes 0 to BOTH DACs and verifies both
      transactions actually returned HAL_OK. On failure it runs
      _I2C1_Recover() and retries, up to 5 attempts. On success it waits
      50 ms for 0 V to settle at the controller input before returning.
    - Motor_Energize(): now calls _EnsureDacsZeroed() FIRST, and only
      closes the contactor if it returns success. The post-close
      _I2C1_Recover() call from the previous revision is removed (it was
      unreachable-by-design as a fix — see above).
    - If zero throttle CANNOT be confirmed: the contactor is deliberately
      NOT closed, and PC13 (onboard LED, active-LOW, confirmed unused) is
      latched on. Rationale: closing the contactor with an unknown
      throttle voltage risks both the fault latch AND a genuine unexpected
      lurch. The rover would not have driven in that state anyway, so
      refusing costs no capability while removing a real hazard.
    - _DiagLedInit() called from Motor_Init().

  How to read the result on hardware — this build is self-diagnosing:
    - Contactor clicks + rover moves      → fixed, hypothesis confirmed.
    - Contactor clicks + still no movement → the DAC write is SUCCEEDING
      (I2C is fine!) but the wheels still don't turn. That definitively
      clears I2C of blame and points at the controllers / level shifter /
      contactor wiring. Next step would be measuring DAC Vout directly
      while commanding throttle.
    - LED lit + NO contactor click        → the firmware could not get a
      confirmed zero write through even after 5 recovery attempts. That
      confirms a genuine I2C/DAC hardware-layer fault (wiring, DAC power,
      address strapping) rather than a timing/ordering problem.
    Each outcome eliminates a different half of the remaining problem
    space, so this build produces useful information even if it doesn't
    fix the symptom.

  Status: TESTED — CAUSED A HARD DEADLOCK, IMMEDIATELY PARTIALLY REVERTED.
          Outcome was the third case above (LED lit, no contactor click),
          but it did NOT clear across resets or power cycles: the rover
          became completely unable to arm, permanently. See "DEADLOCK"
          entry immediately below.

━━━━━━━━━━━━━━━━━━━━━━━━━━━━━━━━━━━━━━━━━━━━━━━━━━━━━━━━━━━━━━━━━━━━━━━━━━━━━━
  DEADLOCK — Gating the Contactor on I2C Success (caused by the fix above;
  fixed same session)
━━━━━━━━━━━━━━━━━━━━━━━━━━━━━━━━━━━━━━━━━━━━━━━━━━━━━━━━━━━━━━━━━━━━━━━━━━━━━━

  Symptom after flashing the "prove zero throttle before energising" build:
  PC13 blue LED solid on, contactor never closes at all, nothing works, and
  — critically — this did NOT clear after repeated resets and power cycles.
  Strictly worse than every prior state, since previously a reset always
  restored full function.

  Root cause: Motor_Energize() had been made to `return` early (refusing to
  close the contactor) whenever _EnsureDacsZeroed() failed. If the MCP4725
  DAC board draws its power from a rail that the CONTACTOR ITSELF switches,
  this is circular and unbreakable:

      contactor stays open  →  DAC has no power
              →  DAC cannot ACK on I2C
              →  _EnsureDacsZeroed() fails
              →  Motor_Energize() refuses to close the contactor
              →  (repeat forever, reset does not help)

  The DAC's power topology was never actually confirmed — it's listed as
  unknown in Rover_study.md §9.3 ("Power supply voltages ... unknown"). The
  symptom (permanent, reset-immune) is strong evidence it IS downstream of
  the contactor.

  Broader lesson, independent of the power topology: NEVER gate the
  machine's ability to arm on an I2C transaction succeeding. I2C is the
  least reliable link in this system and the exact thing under
  investigation; making arming depend on it converts any I2C fault into a
  total, unrecoverable brick. Safety interlocks must fail in a direction
  the operator can recover from.

  Fix — Core/Src/motor.c:
    - Motor_Energize() closes the contactor UNCONDITIONALLY again. The
      zeroing attempt is now best-effort: on failure it lights the LED to
      report, but no longer blocks arming.
    - Added a SECOND _EnsureDacsZeroed() call AFTER the contactor closes
      and settles. If the DAC really is powered downstream of the
      contactor, this is the first instant it can respond — so in that
      topology this is the call that actually lands. It clears the LED on
      success (_DiagLedOff() added), so LED state now reports the outcome
      of the post-contactor attempt.
    - _EnsureDacsZeroed() retry count cut 5 → 2 and inter-attempt delay
      100ms → 50ms, since it now runs twice per energize and must not
      stall arming.
    - _WaitForDacsReady() timeout cut 2s → 300ms: it runs in Motor_Init()
      while the contactor is still open, so in the downstream-power
      topology it can never succeed there and was just adding up to 2
      seconds of dead time to every single boot.

  Status: TESTED AND CONFIRMED WORKING. Contactor arms normally again and
          the DACs now work correctly. This build RESOLVED the long-running
          cold-boot no-movement problem — see the RESOLVED entry below for
          the full explanation.

━━━━━━━━━━━━━━━━━━━━━━━━━━━━━━━━━━━━━━━━━━━━━━━━━━━━━━━━━━━━━━━━━━━━━━━━━━━━━━
██  RESOLVED — COLD-BOOT "NO MOVEMENT / DAC DEAD" PROBLEM                  ██
██  Confirmed working on hardware. This is the entry to read first.        ██
━━━━━━━━━━━━━━━━━━━━━━━━━━━━━━━━━━━━━━━━━━━━━━━━━━━━━━━━━━━━━━━━━━━━━━━━━━━━━━

  ── THE SYMPTOM ─────────────────────────────────────────────────────────

  After a cold power-up, the contactor clicked and the FlySky RC worked
  (arm/disarm responded), but the wheels would not move in any direction.
  Pressing the STM32's physical RESET button made everything work
  perfectly for the rest of that session. Power cycle → broken again.

  ── THE ACTUAL CAUSE ────────────────────────────────────────────────────

  The firmware was trying to talk to the MCP4725 DACs at a point in the
  boot sequence when the DACs were not yet able to respond, and those
  failed transactions left the I2C bus in a wedged state that never
  recovered on its own — so every later DAC write failed too, and the
  throttle output stayed at 0 V forever.

  Sequence on a COLD BOOT (broken):
    1. STM32 powers up and starts executing within milliseconds.
    2. Motor_Init() immediately fires I2C writes at the DACs to zero the
       throttle — while the DACs are not yet able to answer.
    3. Those writes fail. Critically, a failed transaction against a
       not-yet-ready I2C slave can leave SDA held low / the I2C1
       peripheral latched in an error state. The bus is now WEDGED.
    4. The contactor closes. Everything downstream is now powered.
    5. But the bus is still wedged from step 3 — so every DAC write from
       the main control loop also fails. DAC output never changes.
       Throttle stays at 0 V → no movement, forever.

  Sequence after pressing RESET (worked, and this is the clue that cracked
  it):
    1. The DACs were ALREADY powered and settled from the previous
       session — an STM32 reset does not power-cycle them.
    2. Motor_Init()'s I2C writes therefore SUCCEED on the first try.
    3. The bus never wedges. Every subsequent write works. Full movement.

  That is the whole puzzle: reset "fixed" it not because it reset the
  STM32, but because by the time a human pressed the button, the DAC side
  had long since become ready — so the early writes that normally wedge
  the bus succeeded instead.

  ── WHY EARLIER FIX ATTEMPTS ALL FAILED ─────────────────────────────────

  Five attempts failed because every one of them tried to fix things
  BEFORE or AT the point the contactor closes, and none of them ever
  VERIFIED that a DAC write actually landed afterwards:

    1. _WaitForDacsReady() polling HAL_I2C_IsDeviceReady() in Motor_Init()
       — the readiness probe is itself a real I2C transaction, so it could
       wedge the bus exactly like the write it was trying to protect.
    2. 3s delay + NVIC_SystemReset() on cold boot — a reset only clears
       the STM32's own state; it cannot make an external slave release a
       held-low line, and cannot un-wedge the bus.
    3. _I2C1_BusRecovery() bit-banging at boot — ran before the DAC side
       was ready, so it cleared a bus that then simply got re-wedged.
    4. 3s delay THEN bus recovery — same problem, just later.
    5. Gating the contactor on DAC success — caused a hard deadlock (see
       DEADLOCK entry above) and had to be reverted immediately.

  ── WHAT ACTUALLY FIXED IT ──────────────────────────────────────────────

  Core/Src/motor.c, Motor_Energize(). The working ingredient is doing the
  DAC zeroing AFTER the contactor has closed and settled, and — the part
  that matters most — VERIFYING the write actually returned HAL_OK, with
  I2C bus recovery and retry if it did not:

      void Motor_Energize(void)
      {
          if (is_energized) return;

          /* best effort, must NOT block arming */
          if (!_EnsureDacsZeroed()) _DiagLedOn();

          HAL_GPIO_WritePin(Contactor_GPIO_Port, Contactor_Pin, GPIO_PIN_SET);
          _DelayUs(500000U);          /* 500 ms contactor settle */
          is_energized = 1;
          armed        = 1;

          /* THE FIX: retry AFTER the contactor is closed and settled.
           * This is the first moment the DAC side is reliably able to
           * respond — and unlike every earlier attempt, this one CHECKS
           * that the write landed and runs bus recovery + retries if not. */
          if (_EnsureDacsZeroed()) _DiagLedOff();
      }

  The two supporting pieces that make that line work:

    · _WriteDacChecked() — returns the HAL status instead of discarding
      it. The original _WriteDac() threw the return value away, which is
      precisely why a wedged bus could go undetected indefinitely. This
      gap existed from the very first version of motor.c and was the
      single biggest obstacle to diagnosing this — the firmware had no
      idea its writes were failing.

    · _EnsureDacsZeroed() — writes 0 to both DACs, checks BOTH statuses,
      and on failure runs _I2C1_Recover() (de-init I2C1, bit-bang 9 SCL
      pulses to force any stuck slave to release the bus, manual STOP,
      re-init I2C1) then retries. This is what un-wedges a bus that got
      stuck during the early boot writes.

  In short: the earlier bus-recovery code was RIGHT, but it was being run
  at the wrong time and its result was never checked. Moving it after the
  contactor closes and verifying the outcome is what closed the issue.

  ── CONFIDENCE / WHAT IS STILL INFERENCE ────────────────────────────────

  CONFIRMED (observed on hardware):
    · The current build works — DACs respond, all movement works.
    · The deadlock in the previous build was caused by gating the
      contactor on I2C success (direct logical consequence of that code).

  STRONGLY INFERRED (fits all evidence, NOT independently measured):
    · That the DACs are unable to respond at Motor_Init() time on a cold
      boot — most likely because the DAC board is powered from a
      contactor-switched rail. This was never confirmed with a multimeter.
      Rover_study.md §9.3 still lists the power rails as unknown.

  STILL OPEN (bundled in the working build, individual contribution not
  isolated — do NOT assume any of these are load-bearing):
    · The 3s cold-boot delay in main.c (RCC_FLAG_PORRST/BORRST gated).
    · _I2C1_BusRecovery() called at boot in main.c.
    · _WaitForDacsReady() (300ms cap) in Motor_Init().
    Each could be doing real work or could be dead weight. If anyone wants
    a cleaner boot, remove them ONE AT A TIME with a test between each —
    never several at once (that mistake cost several debugging cycles in
    this session; see the ROLLBACK entry).

  ── STILL WORTH DOING ───────────────────────────────────────────────────

  Measure Vdd at the MCP4725 with the contactor OPEN vs CLOSED. If it
  reads 0 V with the contactor open, that confirms the inference above,
  closes out the unknown in Rover_study.md §9.3, and would justify
  simplifying the boot path (all DAC setup belongs after energising, and
  the boot-time delay/recovery code could then be removed with
  confidence).

━━━━━━━━━━━━━━━━━━━━━━━━━━━━━━━━━━━━━━━━━━━━━━━━━━━━━━━━━━━━━━━━━━━━━━━━━━━━━━
██  RESOLVED — ENCODER READING BROUGHT ONLINE AND VERIFIED                 ██
██  Confirmed working on hardware. Encoders now report correct RPM.        ██
━━━━━━━━━━━━━━━━━━━━━━━━━━━━━━━━━━━━━━━━━━━━━━━━━━━━━━━━━━━━━━━━━━━━━━━━━━━━━━

  ── THE GOAL ────────────────────────────────────────────────────────────

  The encoders had never been physically connected on the STM32 build. The
  encoder driver (encoder.c) had been written back in Session 1 and was
  already being called every loop tick from main.c — Encoder_Init() and
  Encoder_Update() were running — but nothing displayed the result, so
  there was no way to know whether it worked. This was therefore an OUTPUT
  problem, not a "write the encoder driver" problem.

  Encoder pins (from Core/Inc/main.h + Rover.ioc — the authoritative
  source; the old Section 2 table was stale and has been corrected):
      Left  encoder A/B  →  PA0 / PA1   (TIM2, 32-bit, Encoder Mode TI12)
      Right encoder A/B  →  PA6 / PA7   (TIM3, 16-bit, Encoder Mode TI12)

  ── HOW THE VALUES WERE GOT OUT — THREE ROUTES TRIED ────────────────────

  ROUTE 1 — SWV / ITM trace over SWO (ABANDONED)
    Plan was to print via ITM to CubeIDE's SWV ITM Data Console. Required
    enabling SYS → Debug = "Trace Asynchronous Sw" in CubeMX (PB3 = SWO),
    which was done and regenerated cleanly (verified: I2C still 100 kHz,
    no duplicate IRQ handlers, USER CODE intact, cold-boot fix preserved).
    ABANDONED because the CubeIDE debug session would not launch at all:
        Failed to start GDB server
        Error in initializing ST-LINK device.
        Reason: (1) Failed to connect to device.
    This failed even with SWV unticked, so it was not an SWV problem.
    Diagnosis showed the ST-Link WAS enumerated on USB (0483:3748) with no
    stale GDB server holding it, and STM32CubeProgrammer connected and
    flashed fine — so the hardware/probe/cabling were all good and the
    fault was specific to the CubeIDE launch configuration. Since SWV
    fundamentally REQUIRES a live debug session, this route was dropped
    rather than fought further.

  ROUTE 2 — USB CDC on the Black Pill's USB-C port (REJECTED, not attempted)
    Rejected after analysis, on a hard technical blocker: USB Full Speed
    needs exactly 48 MHz from PLLQ, and the current clock tree gives 50 MHz
        HSI 16 → PLLM 8 → 2 MHz → PLLN 100 → 200 MHz VCO
                 → PLLP 2 → 100 MHz SYSCLK ✓
                 → PLLQ 4 →  50 MHz USB    ✗ (needs 48)
    On STM32F411 the USB clock can ONLY come from PLLQ (no PLLSAI/CK48M mux
    like the larger F4 parts), so there is no way to have both 100 MHz
    SYSCLK and valid USB. The only valid combination is a 192 MHz VCO →
    96 MHz SYSCLK + 48 MHz USB. That would have dropped HCLK 100 → 96 MHz,
    which silently breaks the TIM5 microsecond timebase (prescaler 99 gives
    0.96 MHz instead of 1 MHz — every delay, the RC timeout, the loop
    period, the contactor debounce and the DAC ramp all 4 % off) and would
    have needed TIM5 prescaler 99 → 95 in the same step, plus USB_DEVICE
    CDC middleware and a large regeneration. Judged far too much
    interconnected change at once for the benefit.

  ROUTE 3 — UART → ESP32 → USB serial monitor  ✅ ADOPTED AND WORKING
    STM32 PA9 (USART1_TX) → ESP32 DevKit V1 GPIO16 (RX2), plus common GND.
    ESP32 runs a pass-through sketch bridging its UART2 to USB, read in the
    Arduino IDE Serial Monitor at 115200.
    Chosen because it needed ZERO CubeMX changes (PA9 was already
    configured as USART1_TX with UART_MODE_TX_RX), no clock change, no
    debugger, and works with the CubeProgrammer flash workflow that was
    already functioning. It also aligns with an existing roadmap item —
    Section 7 already called for "telemetry → UART to ESP32/ESP8266".

  ── CRITICAL WIRING RULE ────────────────────────────────────────────────

  ONE DIRECTION ONLY: STM32 PA9 → ESP32 GPIO16, plus GND.
  NOTHING may be connected to STM32 PA10. PA10 is USART1_RX and carries the
  FlySky iBUS signal; driving it from the ESP32 would collide with the RC
  link and break control while motors are armed.
  Both devices are 3.3 V logic, so PA9 connects directly — no level shifter.

  ── CODE ADDED ──────────────────────────────────────────────────────────

  Core/Inc/encoder.h + Core/Src/encoder.c
    · Encoder_GetCount_L() / Encoder_GetCount_R() — expose the raw extended
      counter values (return prev_count_l / prev_count_r, the values
      Encoder_Update() last sampled). Deliberately printed ALONGSIDE RPM:
      raw counts prove the hardware and wiring work, RPM proves the maths
      works. Counts moving with RPM wrong = firmware bug; counts frozen =
      wiring/pin problem. Separating those saves a debugging cycle.

  Core/Src/main.c
    · _DbgPutc() — writes USART1->DR DIRECTLY, deliberately NOT via
      HAL_UART_Transmit(). REASON: HAL_UART_Transmit() takes
      __HAL_LOCK(huart1) and holds it for the entire blocking send; if the
      iBUS IDLE interrupt fires in that window, the HAL_UART_Receive_DMA()
      inside IBUS_IdleCallback() returns HAL_BUSY, the RX DMA is never
      restarted and RC frames are dropped. With iBUS frames every ~7 ms and
      a multi-ms send, collisions would be frequent — unacceptable with
      motors powered. TX and RX are independent paths inside the USART, so
      a direct DR write cannot disturb the RX DMA and never touches the
      HAL lock.
      The TXE busy-wait is hardware-bounded (~87 us/char at 115200) since
      the transmitter always drains whether or not anything is listening —
      so it can never stall the 20 Hz loop, and it is safe even with
      nothing connected to PA9.
    · _DbgPuts() — string wrapper.
    · _FmtRpm() — formats a float RPM as e.g. "+12.50" WITHOUT using %f.
      newlib-nano omits float formatting unless -u _printf_float is added
      to the linker flags, and silently prints nothing or garbage
      otherwise. Formats via scaled integers instead to sidestep it.
    · Debug print block in the main loop, rate-limited to ~4 Hz (every 5th
      tick of the 20 Hz loop). At full 20 Hz a ~70-char line would cost
      ~10 % of every loop cycle; at 4 Hz it is ~2 % and far more readable.

  esp32_bridge/esp32_bridge.ino  (new file, outside the STM32 project)
    ESP32 DevKit V1 pass-through bridge: Serial2 (GPIO16) → Serial (USB).
    Includes a watchdog message if no data arrives for 3 s, which
    distinguishes "bridge broken" from "STM32 not transmitting" — those
    otherwise look identical (a blank screen) and waste debugging time.
    NOTE: GPIO16/17 are free on WROOM-32 (DevKit V1). On WROVER modules
    those pins are used for PSRAM — use GPIO25/26 there instead.

  ── OUTPUT FORMAT ───────────────────────────────────────────────────────

      CMD L+6.00 R+6.00 | ENC L+5.92 R+6.05 | cnt 412 419

      CMD = commanded wheel RPM from the pipeline
      ENC = measured wheel RPM from the encoders
      cnt = raw quadrature counter values (left, right)

    Printing commanded and measured side by side answers several questions
    in one line: is the encoder wired, is its direction correct, and does
    the RPM maths agree with what was asked for. It is also exactly the
    signal needed later for PID tuning.

    Interpreting it:
      · CMD and ENC same sign, magnitudes close   → working correctly
      · ENC sign OPPOSITE to CMD on one wheel     → that encoder's A/B
                                                    phases are swapped
      · One side stuck at +0.00, cnt frozen       → that encoder not wired
      · cnt moves but ENC stays 0.00              → turning too slowly;
                                                    ENC_STOPPED_US (500 ms)
                                                    is zeroing the reading

  ── RESULT ──────────────────────────────────────────────────────────────

  CONFIRMED WORKING on hardware — encoders read RPM correctly.

  ── STILL OPEN (known, deliberately deferred) ───────────────────────────

  · TIM3 (right encoder) 16-bit overflow is STILL untracked. TIM3_IRQn
    remains masked at the NVIC, so Encoder_TIM3_OvfCallback() never fires
    and enc_r_overflow never updates. Expect ONE large bogus ENC R value
    roughly every 82 s of continuous rotation at full wheel speed (~4.5 min
    at the 30 % SWC cap), then normal readings resume. Left wheel (TIM2,
    32-bit) is unaffected — it would not wrap for ~2 months.
    Periodic spikes on R ONLY are this known issue, NOT a wiring fault.
    The correct fix is already worked out: POLL the Update flag inside
    Encoder_Update(), do NOT re-enable the interrupt (that approach caused
    the Bug #5 full MCU lockup — HAL_TIM_Encoder_Start_IT() enables CC1/CC2
    edge interrupts, not Update, so an ISR that only clears the Update flag
    never clears the flag that woke it and re-fires forever).
  · Low-speed resolution is inherently coarse: one count = 0.5 RPM with the
    50 ms sampling window, so slow running looks steppy. Fine for
    telemetry; relevant when PID tuning starts.
  · The SYS → Debug = "Trace Asynchronous Sw" CubeMX setting is now unused
    (SWV route abandoned). Harmless to leave; can be reverted to plain
    "Serial Wire" whenever convenient.

━━━━━━━━━━━━━━━━━━━━━━━━━━━━━━━━━━━━━━━━━━━━━━━━━━━━━━━━━━━━━━━━━━━━━━━━━━━━━━
SECTION 6 — CURRENT STATE OF ALL FILES
━━━━━━━━━━━━━━━━━━━━━━━━━━━━━━━━━━━━━━━━━━━━━━━━━━━━━━━━━━━━━━━━━━━━━━━━━━━━━━

  File                          | Status
  ------------------------------|------------------------------------------
  Core/Inc/config.h             | Complete, verified against BBB config.py
  Core/Inc/motor.h              | Complete
  Core/Src/motor.c              | ✅ WORKING/CONFIRMED. 3-byte DAC, 100kHz. Dir-change DAC soft-start ramp (fixed reverse-engage). _WriteDacChecked() + _EnsureDacsZeroed() + _I2C1_Recover() — Motor_Energize() closes the contactor UNCONDITIONALLY (never gate arming on I2C — see DEADLOCK) and re-zeroes/verifies the DACs AFTER it closes, which is what RESOLVED the cold-boot issue. PC13 diag LED.
  Core/Inc/encoder.h            | Encoder_GetCount_L/R() for bench verification. Encoder_TIM3_OvfCallback REMOVED (no longer exists — wrap handled arithmetically).
  Core/Src/encoder.c            | Encoders read RPM correctly ✅. TIM3 16-bit wrap now handled by _Delta16() modular arithmetic — no interrupt, no overflow counter. Both timers started non-IT. NOT YET FLASHED after the TIM3 fix.
  Core/Inc/ibus.h               | Reverted IBUS_IsSignalOk() removal 2026-07-30 — otherwise unchanged (IBUS_RxneCallback removed, Session 1/2).
  Core/Src/ibus.c               | Complete (DMA + IDLE interrupt version; _ToFloat() signed-subtraction fix 2026-07-30 — see Bug #4). This is the ONLY Session 3 code change still active.
  Core/Inc/pipeline.h           | Complete
  Core/Src/pipeline.c           | Complete
  Core/Src/main.c               | ✅ WORKING/CONFIRMED. Auto-energize, 20 Hz loop. Debug telemetry over USART1 TX (PA9) → ESP32 → USB @4Hz: _DbgPutc/_DbgPuts/_FmtRpm. Also carries a cold-boot-only 3s delay (RCC_FLAG_PORRST/BORRST) + _I2C1_BusRecovery() before peripheral init — these are of UNPROVEN individual value (see RESOLVED entry "STILL OPEN"); remove one at a time with a test between if simplifying.
  esp32_bridge/esp32_bridge.ino | ✅ WORKING/CONFIRMED. ESP32 DevKit V1 (WROOM-32) UART→USB pass-through bridge. Serial2 GPIO16 ← STM32 PA9. NOT part of the STM32 build — upload separately via Arduino IDE.
  Core/Src/stm32f4xx_it.c       | IDLE hook for iBUS in USER CODE. TIM3_IRQHandler REMOVED — TIM3 now has no handler and no NVIC entry by design (comment left in place warning against re-adding it).
  Core/Src/stm32f4xx_hal_msp.c  | Reverted to pre-Session-3 state 2026-07-30 — no TIM3 NVIC enable (USART1 NVIC manually added, Session 2, unchanged).

━━━━━━━━━━━━━━━━━━━━━━━━━━━━━━━━━━━━━━━━━━━━━━━━━━━━━━━━━━━━━━━━━━━━━━━━━━━━━━
SECTION 7 — PENDING TASKS
━━━━━━━━━━━━━━━━━━━━━━━━━━━━━━━━━━━━━━━━━━━━━━━━━━━━━━━━━━━━━━━━━━━━━━━━━━━━━━

  [x] Verify motor throttle responds after 100 kHz I2C fix — DONE.
      CONFIRMED WORKING: DACs respond correctly, forward/reverse/steering
      all functional. Took much longer than expected because a separate
      cold-boot I2C wedging problem masked it — see the RESOLVED entry
      above Section 6.

  [ ] Measure MCP4725 Vdd with contactor OPEN vs CLOSED
      → Confirms/refutes the one remaining inference behind the RESOLVED
        fix, and closes an "unknown" in Rover_study.md §9.3
      → If 0 V when open: DAC is on a contactor-switched rail, and the
        boot-time delay/recovery code in main.c can likely be removed

  [ ] Optional cleanup: trim unproven boot-time code in main.c (3s cold-boot
      delay, _I2C1_BusRecovery(), _WaitForDacsReady())
      → Remove ONE AT A TIME with a cold-boot test between each
      → Do NOT batch these — batching changes is what caused the worst
        regressions in this session (see ROLLBACK / DEADLOCK entries)

  [x] Connect encoders and verify the STM32 reads RPM — DONE, CONFIRMED
      WORKING. Values visible over UART → ESP32 → Arduino Serial Monitor.
      See the RESOLVED-ENCODER entry above Section 6 for the full story
      (including the two routes tried and rejected first).

  [~] TIM3 16-bit overflow tracking — FIXED IN SOURCE, AWAITING TEST
      → Implemented as a single isolated change. Approach used is BETTER
        than the polling plan originally sketched here: instead of polling
        the Update flag, the wrap is handled purely arithmetically by
        _Delta16() in encoder.c — take the counter difference modulo 2^16
        and read the upper half of the range as negative.
      → Why arithmetic beats polling: no flag to manage, no dependence on
        WHEN the poll happens, no stale direction-bit read, no overflow
        counter, no startup-flag edge case (HAL_TIM_Encoder_Init sets UG
        which leaves UIF set — a polling version would have had to clear
        that first or spuriously count one wrap at boot), and no critical
        section. Correct as long as the wheel moves <32767 counts between
        samples; actual is ~40, so ~800x margin.
      → Also removed: enc_r_overflow, _read_count_l/_read_count_r,
        Encoder_TIM3_OvfCallback (from both .c and .h), and the
        TIM3_IRQHandler in stm32f4xx_it.c. TIM3 is now started non-IT.
        A comment was left in stm32f4xx_it.c warning against re-adding a
        TIM3 handler (the Bug #5 interrupt-storm trap).
      → Encoder_GetCount_L/R() now return accumulated signed totals rather
        than the raw hardware counter, so the telemetry count no longer
        visibly jumps at a wrap.
      → VERIFY: run continuously for >90 s at full wheel speed (or >5 min
        at the 30 % cap) and confirm no ±32768 spike appears on ENC R.
        Also confirm reverse still gives negative ENC values on both
        wheels (the modular arithmetic must work in both directions).

  [ ] Fail to brake on repeated DAC write failure (SAFETY GAP)
      → Motor_SetSpeeds() uses the fire-and-forget _WriteDac(), which
        discards the HAL status. If the I2C bus wedges mid-drive, the DAC
        keeps its last value and the WHEELS KEEP TURNING at the last
        commanded speed.
      → Same hazard class as the cold-boot problem but while moving. The
        checked variant (_WriteDacChecked) already exists and is used in
        _EnsureDacsZeroed(); the driving path just doesn't use it.
      → Becomes more pressing when the BNO055 is added, since it is a
        known I2C clock-stretcher sharing the same bus.

  [ ] Motor.c blocking delays aborting to brake on RC signal loss —
      REVERTED 2026-07-30, see Rollback
      → IBUS_IsSignalOk() / _DelayUsSafe() were written and are believed
        correct, but reverted along with the TIM3 change so root causes
        could be isolated. The original risk this was meant to address is
        still real: direction-change (150ms) and reverse-brake (500ms)
        holds in motor.c are unconditional busy-waits that can delay the
        400ms RC-loss failsafe by up to ~500ms during a maneuver.
      → Re-attempt this separately, AFTER Bug #4 is confirmed working
        alone, not bundled with other changes.

  [x] Fix reverse / left-steering not responding — DONE 2026-07-30, see Bug #4
      → Root cause: unsigned-subtraction wraparound in ibus.c _ToFloat().
      → This is the ONLY Session 3 change currently in the code. Rebuilt
        and flash-tested once already (see Rollback) but bundled with
        other changes that regressed forward driving — needs a clean
        re-test with ONLY this change in place to confirm it in isolation.

  [ ] Implement imu.c / imu.h — BNO055 over I2C
      → Euler angles + 9-axis data
      → I2C address: 0x28 or 0x29

  [ ] Implement pid.c / pid.h — PID closed-loop speed controller
      → Encoder RPM feedback → DAC output adjustment
      → Mirror BBB motor_controller_closed_loop.py

  [ ] Implement GPS module — ZED-F9P over UART
      → 115200 baud, NMEA/UBX parsing
      → Requires second UART (USART2 or USART6)

  [ ] Set up telemetry — replace UDP → UART to ESP32/ESP8266 WiFi module
      → JSON payload: IMU + encoder + motor state at 20 Hz

━━━━━━━━━━━━━━━━━━━━━━━━━━━━━━━━━━━━━━━━━━━━━━━━━━━━━━━━━━━━━━━━━━━━━━━━━━━━━━
SECTION 8 — KEY TECHNICAL LESSONS
━━━━━━━━━━━━━━━━━━━━━━━━━━━━━━━━━━━━━━━━━━━━━━━━━━━━━━━━━━━━━━━━━━━━━━━━━━━━━━

  1. CubeMX does NOT add NVIC enable for UARTs unless the NVIC panel is
     explicitly configured. Always check HAL_UART_MspInit() for missing
     HAL_NVIC_EnableIRQ() calls when interrupts are not firing.

  2. DMA must be enabled in CubeMX before calling HAL_UART_Receive_DMA().
     If hdmarx is NULL, the call returns HAL_ERROR silently — no crash,
     no assertion, just no data. Always verify DMA is in MX_DMA_Init().

  3. MX_DMA_Init() must be called BEFORE any peripheral init (MX_I2C1_Init,
     MX_USART1_UART_Init) in main.c. CubeMX handles this automatically
     when DMA is added via the GUI.

  4. After CubeMX code regeneration, check stm32f4xx_it.c for duplicate
     IRQ handlers. CubeMX will add its own handler for any configured IRQ,
     and any existing USER CODE handler for the same IRQ must be removed.

  5. STM32F4 IDLE flag is cleared by reading SR then DR. The HAL macro
     __HAL_UART_CLEAR_IDLEFLAG() performs this correctly. Never write
     to the flag register directly.

  6. MCP4725 Write DAC Register (0x40) requires 3 bytes total:
       [command=0x40] [D11:D4] [D3:D0 << 4]
     Python smbus2 write_i2c_block_data(addr, 0x40, [hi, lo]) matches this.
     Sending only 2 bytes (missing command byte) causes 0x00 fast-write,
     which always outputs 0 V.

  7. I2C pull-up resistor vs speed: 4.7 kΩ pull-ups → rise time ~470 ns.
     This is within Standard Mode (100 kHz) limit of 1000 ns,
     but exceeds Fast Mode (400 kHz) limit of 300 ns.
     Rule: for 4.7 kΩ pull-ups, always use Standard Mode 100 kHz.
     For Fast Mode 400 kHz: use 2.2 kΩ or 1 kΩ pull-ups.

  8. Auto-energize on boot: clicking the contactor at startup serves as a
     hardware "system ready" indicator — audible confirmation that firmware
     has initialised successfully and motor power is armed.

  9. KNOWN CONTROLLER QUIRK (not a firmware bug — confirmed 2026-07-30 by
     user, present on BOTH BeagleBone and STM32): the BLDC/e-scooter motor
     controller will not engage reverse from a dead stop. The operator must
     briefly command forward first, then reverse, for reverse to actually
     take effect — even though the REV-pin-then-delay sequence (brake
     500ms → release → REV pin HIGH → 150ms settle → 20ms → throttle
     written) is correct and already matches the BBB implementation
     exactly. This is a characteristic of the controller itself (almost
     certainly needs to sense actual prior rotation before permitting
     reversed commutation), not something a firmware delay can fix — don't
     waste time re-tuning REVERSE_BRAKE_US or the dir-change settle time
     to try to eliminate this; it's not a timing problem.

     REVISED same day, more precise info from user: on BBB (after later
     changes), simply HOLDING the reverse command steady for 2-3 seconds
     was enough — no manual toggling needed, even for an abrupt full-
     throttle reverse command. On STM32, sustained holding alone was NOT
     enough; only a GRADUAL pull of the stick, or manually toggling
     forward/reverse repeatedly, got reverse to engage. Both STM32
     workarounds have one thing in common: they make the throttle value
     ramp up gradually instead of jumping straight from 0 to the full
     commanded value in one step (which is exactly what Motor_SetSpeeds()
     was doing — a single _WriteDac() call to the final value right after
     the direction-change delay). This points at the controller rejecting
     an ABRUPT full-throttle-in-reverse command specifically, not simply
     needing more elapsed time. See the DAC ramp experiment in Section 9
     for the fix attempt — this lesson entry will be updated once it's
     verified on hardware.

━━━━━━━━━━━━━━━━━━━━━━━━━━━━━━━━━━━━━━━━━━━━━━━━━━━━━━━━━━━━━━━━━━━━━━━━━━━━━━
SECTION 9 — CHRONOLOGICAL SESSION SUMMARY
━━━━━━━━━━━━━━━━━━━━━━━━━━━━━━━━━━━━━━━━━━━━━━━━━━━━━━━━━━━━━━━━━━━━━━━━━━━━━━

  SESSION 1 (Previous context — all module code written)
  ──────────────────────────────────────────────────────
  · Read and understood all BBB source files
  · Mapped all BBB peripherals to STM32F411CEU6 pins
  · Decided encoder strategy: period-based (not counter) for RPM resolution
  · Guided CubeMX configuration (TIM2/3/4/5, I2C1, USART1, DMA, GPIO)
  · Wrote all modules: config.h, motor.c/.h, encoder.c/.h, ibus.c/.h,
    pipeline.c/.h, and updated main.c control loop
  · User generated CubeMX code, applied module files
  · Identified 11 build errors → fixed all (Contactor typo, extern decls)
  · Clean build achieved

  SESSION 2 (Current context)
  ──────────────────────────────────────────────────────
  · User flashed via ST-Link — first power-on
  · Bug #1 (no contactor click) → implemented auto-energize on boot
  · Contactor confirmed clicking after fix
  · Bug #2 (iBUS not working):
      - Fixed missing USART1 NVIC in HAL_UART_MspInit
      - User added DMA2 Stream2 in CubeMX → DMA now functional
      - Fixed duplicate USART1_IRQHandler after CubeMX regeneration
      - Moved IDLE detection into CubeMX handler USER CODE section
  · iBUS confirmed working (SWD arm/disarm responding)
  · Bug #3 (throttle no effect):
      - Identified missing 0x40 command byte in _WriteDac()
      - Identified I2C speed mismatch (400 kHz with 4.7 kΩ pull-ups)
      - Fixed both: 3-byte DAC command + 100 kHz I2C
  · Exported full conversation to conversation_export.txt (200 messages, 224 KB)
  · Created this WorkLog.txt
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

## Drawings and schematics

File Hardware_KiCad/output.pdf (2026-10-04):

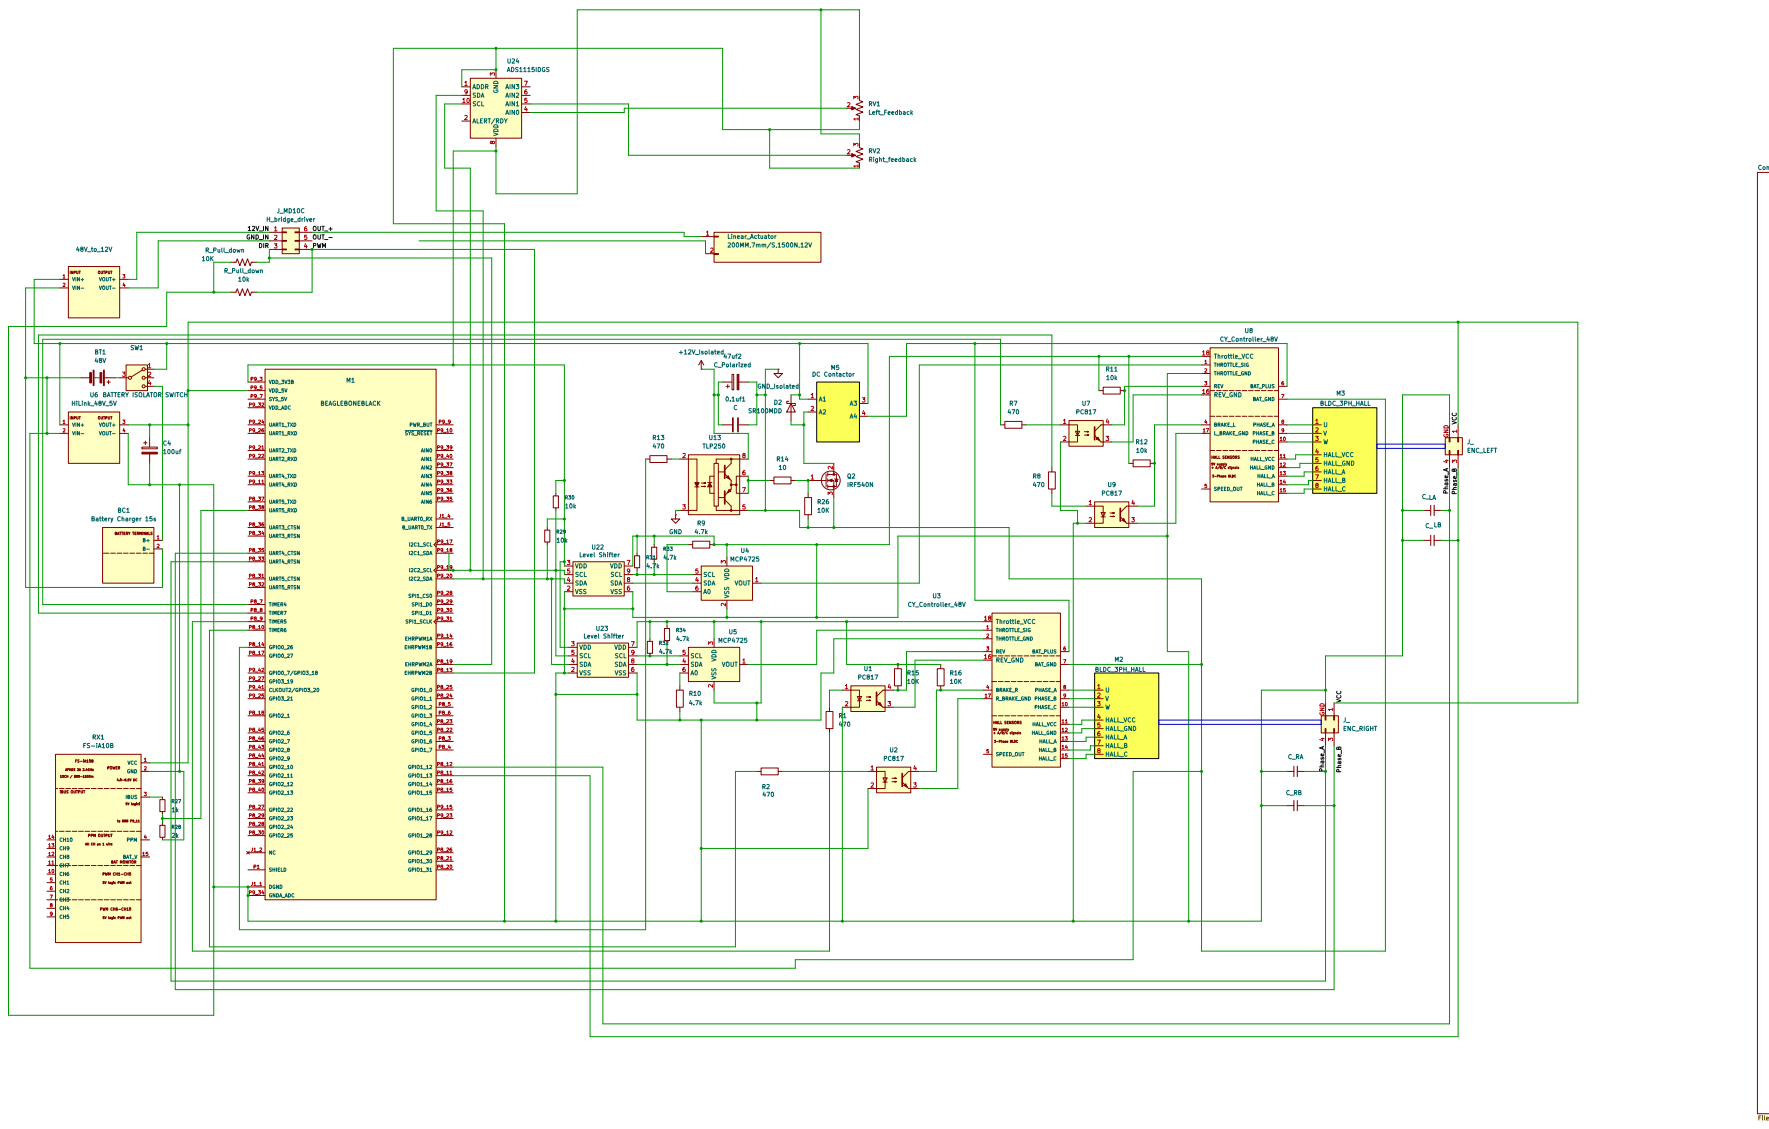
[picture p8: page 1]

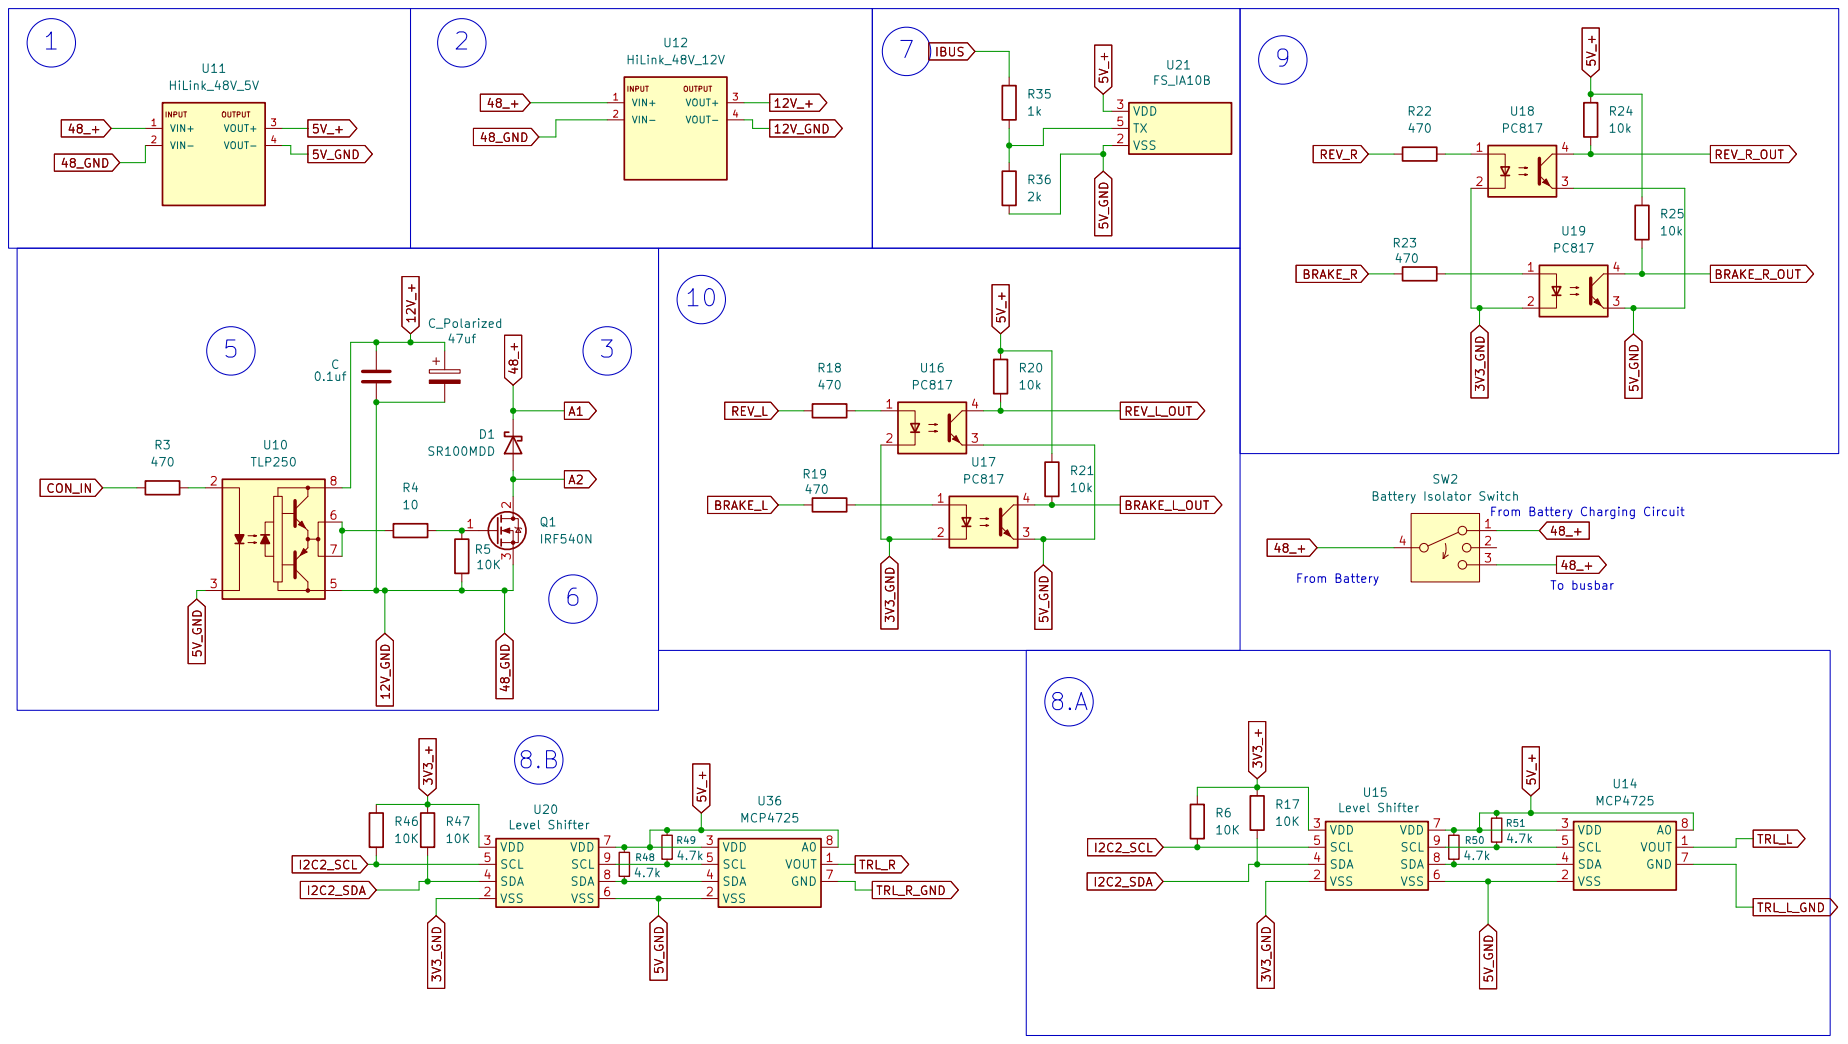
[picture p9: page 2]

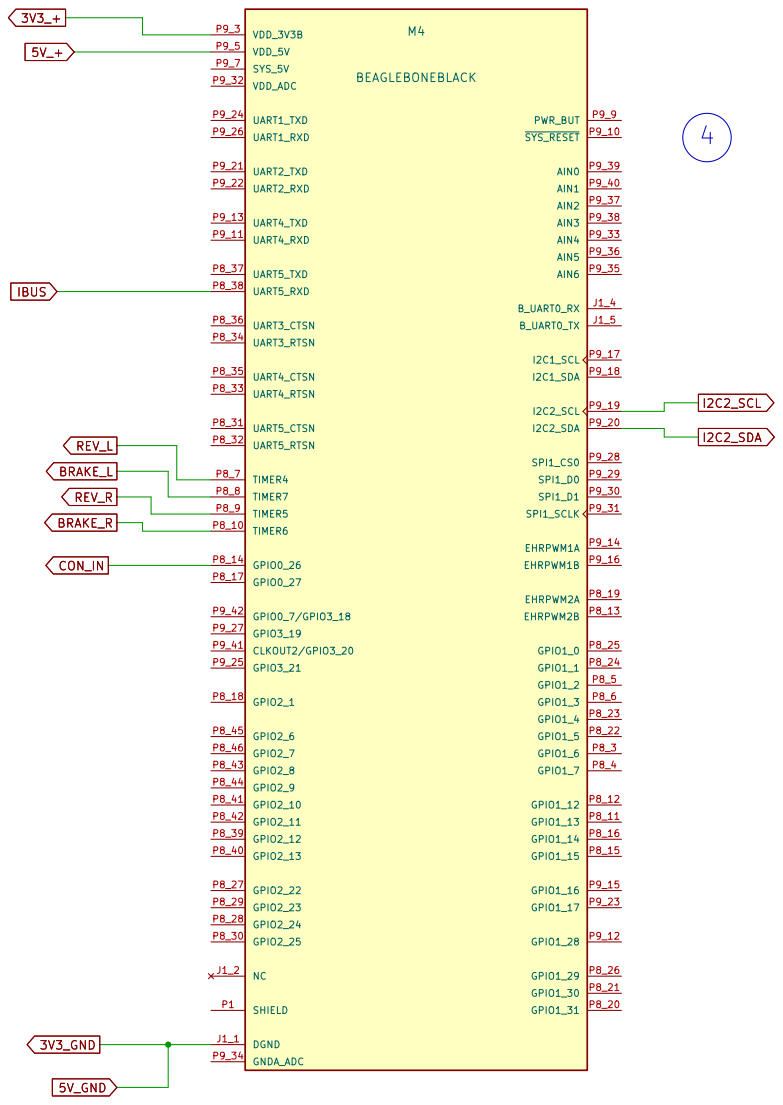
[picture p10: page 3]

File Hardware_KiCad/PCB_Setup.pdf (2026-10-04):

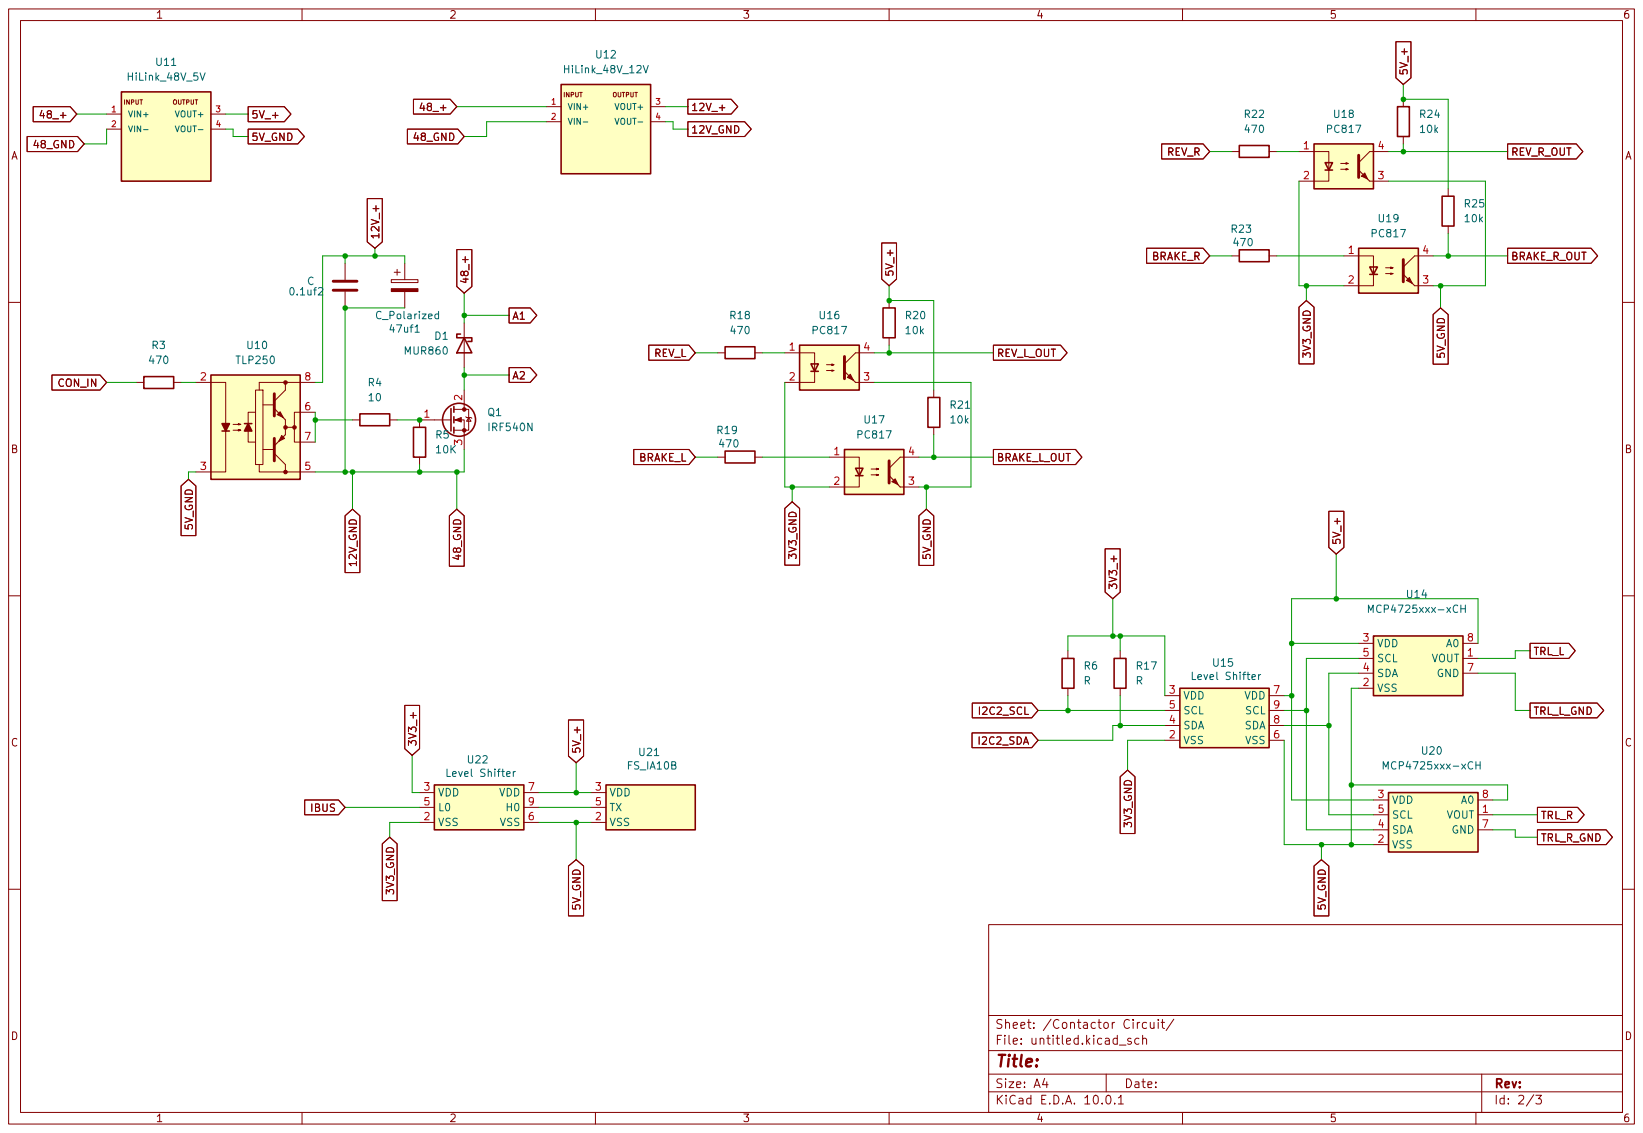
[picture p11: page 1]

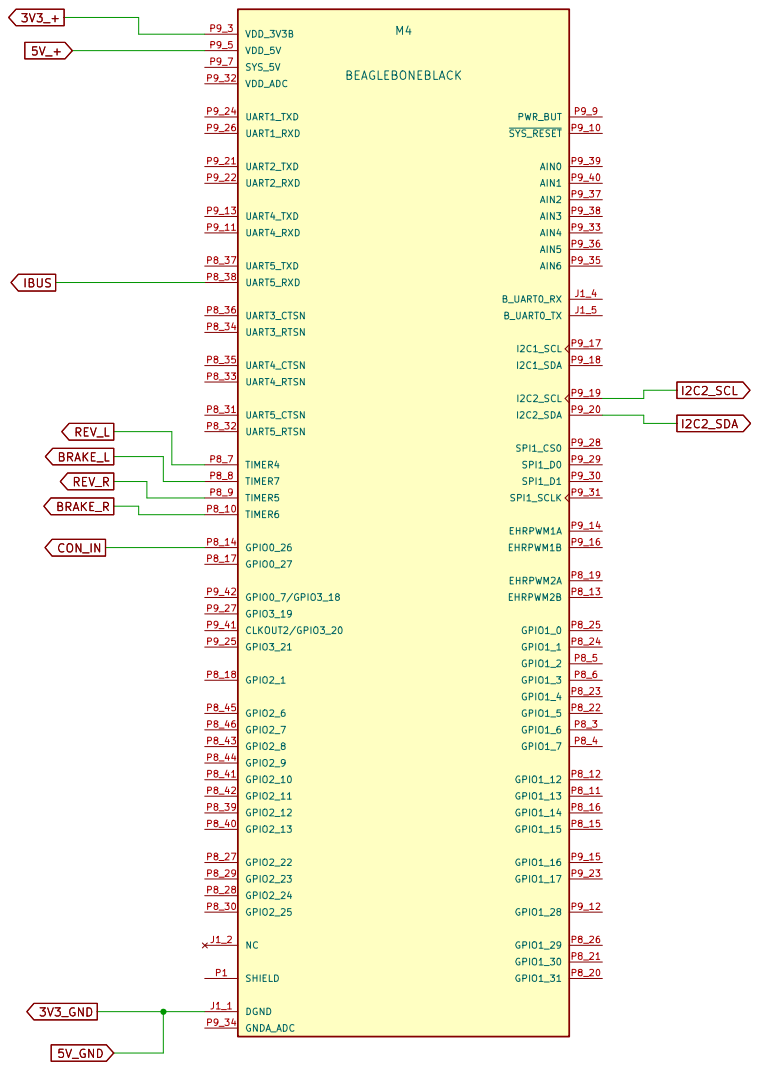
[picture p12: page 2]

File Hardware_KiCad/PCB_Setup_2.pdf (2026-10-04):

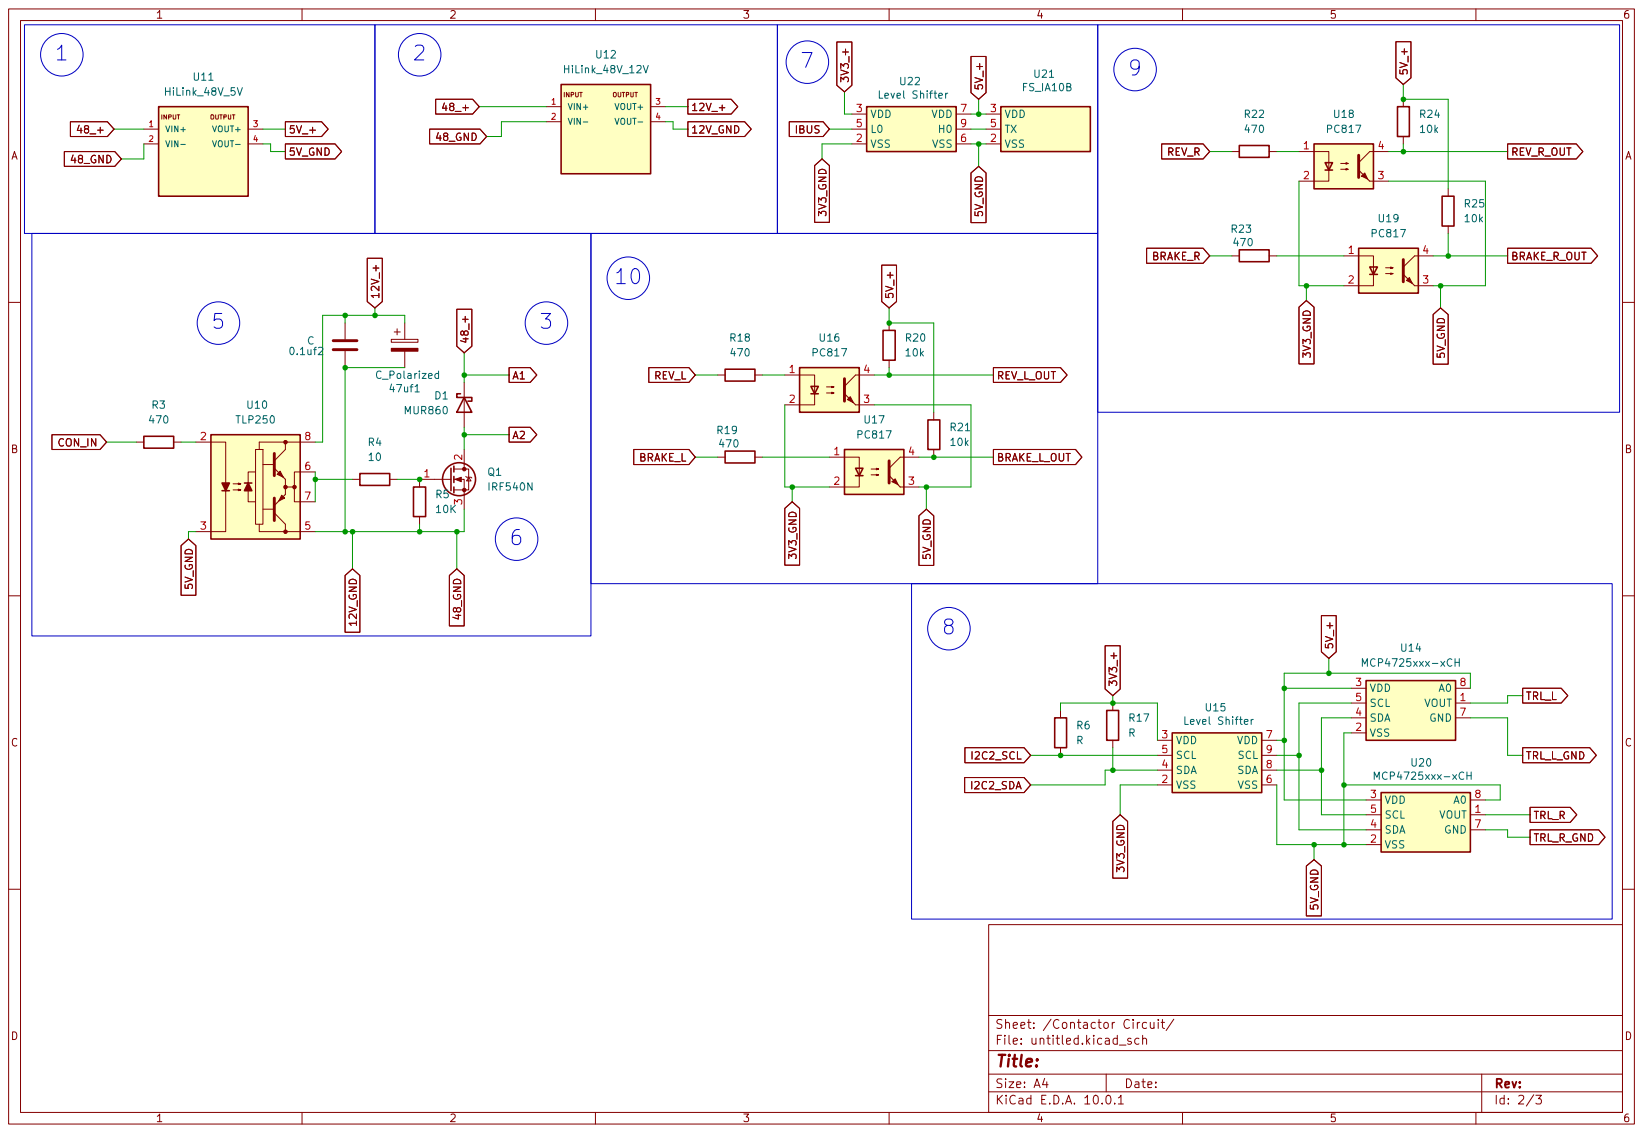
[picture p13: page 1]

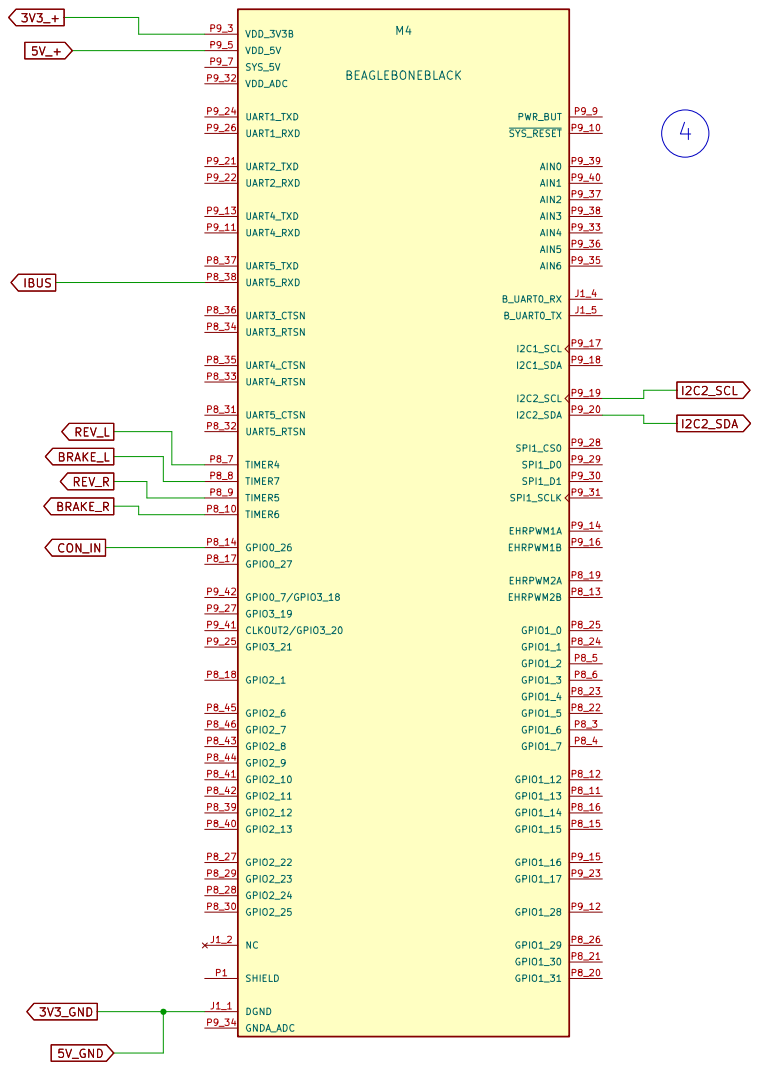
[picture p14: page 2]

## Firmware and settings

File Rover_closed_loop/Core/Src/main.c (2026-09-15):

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
/* Includes ------------------------------------------------------------------*/
#include "main.h"
#include "dma.h"
#include "i2c.h"
#include "tim.h"
#include "usart.h"
#include "gpio.h"

/* USER CODE BEGIN Includes */
/* NOTE: these must stay inside this USER CODE block, not above it — CubeMX
 * regenerates everything outside USER CODE markers from scratch on every
 * "Generate Code", and a prior edit that added these directly above (outside
 * any marker) was silently wiped by today's regeneration for the RPi UART
 * link. Re-added here so they survive the next regeneration too. See
 * scratchpad.md "Missing Includes Wiped by CubeMX Regeneration". */
#include "config.h"
#include "ackermann_config.h"
#include "ibus.h"
#include "rpi_link.h"
#include "motor.h"
#include "encoder.h"
#include "ads1115.h"
#include "actuator.h"
#include "steer_pid.h"
#include "wheel_pid.h"
#include "ackermann.h"
#include <math.h>
#include <stdio.h>
/* USER CODE END Includes */


/* USER CODE BEGIN PV */
/* Contactor edge-detect state — local to main loop */
static uint8_t      prev_swd_on       = 0U;
static uint32_t     last_contactor_ts = 0U;

/* Closed-loop steering state */
static SteerPID_t   steer_pid;
static SteerAngles_t steer;
static uint32_t     prev_loop_ts      = 0U;

/* Centering watchdog (step 6) — see its comment at the call site */
static uint8_t      center_watchdog_active   = 0U;
static uint32_t     center_watchdog_start_ts = 0U;

/* Closed-loop forward wheel-speed state (wheel_pid.c) — see ackermann.h */
static WheelPID_t   wheel_pid_L, wheel_pid_R;
/* USER CODE END PV */

void SystemClock_Config(void);
/* USER CODE BEGIN 0 */

/* ── Debug output over USART1 TX (PA9) → ESP32 → USB serial monitor ───────
 *
 * Writes USART1's data register DIRECTLY rather than going through
 * HAL_UART_Transmit(). This is deliberate and important:
 *
 *   HAL_UART_Transmit() takes __HAL_LOCK(huart1) and holds it for the whole
 *   blocking send. If the iBUS IDLE interrupt fires during that window, the
 *   HAL_UART_Receive_DMA() call inside IBUS_IdleCallback() returns HAL_BUSY,
 *   the RX DMA is never restarted, and RC frames get dropped. With frames
 *   arriving every ~7 ms and a send taking several ms, that would collide
 *   constantly — unacceptable on a machine with powered motors.
 *
 * TX and RX are fully independent paths inside the USART, so writing DR for
 * transmit cannot disturb the iBUS RX DMA, and bypassing HAL means the lock
 * is never touched.
 *
 * The TXE busy-wait is hardware-bounded (~87 us/char at 115200) because the
 * transmitter always drains, whether or not anything is listening on PA9 —
 * so unlike the ITM/SWV approach this can never stall the 20 Hz control
 * loop, and it works with nothing connected at all. */
static void _DbgPutc(char c)
{
    while ((USART1->SR & USART_SR_TXE) == 0U) { }
    USART1->DR = (uint8_t)c;
}

static void _DbgPuts(const char *s)
{
    while (*s != '\0') _DbgPutc(*s++);
}

/* Format an RPM as e.g. "+12.50". Deliberately avoids %f — newlib-nano
 * omits float formatting unless -u _printf_float is added to the linker
 * flags, which silently prints nothing or garbage otherwise. */
static void _FmtRpm(char *out, int n, float rpm)
{
    int32_t v = (int32_t)(rpm * 100.0f);
    char sign = (v < 0) ? '-' : '+';
    if (v < 0) v = -v;
    snprintf(out, n, "%c%ld.%02ld", sign, (long)(v / 100), (long)(v % 100));
}

/* I2C1 bus-clear recovery, run on PB6 (SCL) / PB7 (SDA) as plain open-drain
 * GPIO, BEFORE MX_I2C1_Init() ever reconfigures those pins to I2C
 * alternate-function mode.
 *
 * Why this exists: on a cold boot, the DAC board's own supply rail can
 * still be ramping up when this MCU starts executing. If an I2C
 * transaction is attempted against the DAC while it's only partially
 * powered, the DAC can end up frozen mid-transaction, actively holding
 * SDA low. Neither a hardware NRST reset nor a software NVIC_SystemReset()
 * fixes this — a reset only clears THIS chip's own I2C peripheral state,
 * it cannot force an external slave that's actively driving a line low to
 * let go of it. (Confirmed against STMicroelectronics community reports of
 * the identical symptom on STM32F4 I2C.) The only real fix, per the I2C-bus
 * spec's "bus clear" procedure: manually clock SCL up to 9 times while SDA
 * is released, so the stuck slave's internal shift register finishes
 * clocking out whatever byte it was frozen on and releases the line, then
 * generate a manual STOP condition to leave the bus cleanly idle.
 *
 * Runs unconditionally on every boot (not just cold power-on) — it's fast
 * (a few hundred microseconds) and harmless if the bus is already idle,
 * since without a preceding START condition a healthy slave simply ignores
 * the extra clock edges. */
static void _I2C1_BusRecovery(void)
{
    __HAL_RCC_GPIOB_CLK_ENABLE();

    GPIO_InitTypeDef gpio = {0};
    gpio.Pin   = GPIO_PIN_6 | GPIO_PIN_7;
    gpio.Mode  = GPIO_MODE_OUTPUT_OD;
    gpio.Pull  = GPIO_PULLUP;
    gpio.Speed = GPIO_SPEED_FREQ_LOW;
    HAL_GPIO_Init(GPIOB, &gpio);

    /* Release SDA (external 4.7k pull-up brings it high) — only SCL is
     * actively driven during the clock-out phase. */
    HAL_GPIO_WritePin(GPIOB, GPIO_PIN_7, GPIO_PIN_SET);

    for (int i = 0; i < 9; i++)
    {
        HAL_GPIO_WritePin(GPIOB, GPIO_PIN_6, GPIO_PIN_RESET);
        for (volatile int d = 0; d < 4000; d++) { __NOP(); }
        HAL_GPIO_WritePin(GPIOB, GPIO_PIN_6, GPIO_PIN_SET);
        for (volatile int d = 0; d < 4000; d++) { __NOP(); }
    }

    /* Manual STOP condition: SDA transitions low->high while SCL is high. */
    HAL_GPIO_WritePin(GPIOB, GPIO_PIN_7, GPIO_PIN_RESET);
    for (volatile int d = 0; d < 4000; d++) { __NOP(); }
    HAL_GPIO_WritePin(GPIOB, GPIO_PIN_7, GPIO_PIN_SET);
    for (volatile int d = 0; d < 4000; d++) { __NOP(); }
}

/* USER CODE END 0 */

/**
  * @brief  The application entry point.
  * @retval int
  */
int main(void)
{

  /* MCU Configuration--------------------------------------------------------*/

  /* Reset of all peripherals, Initializes the Flash interface and the Systick. */
  HAL_Init();

  /* USER CODE BEGIN Init */
  /* Bus-recovery alone (see _I2C1_BusRecovery() above) did not resolve the
   * cold-boot no-movement issue on its own. Bringing back a delay on a
   * genuine cold boot ONLY (RCC_FLAG_PORRST/BORRST — not a later manual
   * reset, RCC_FLAG_PINRST) so the DAC board's supply rail is fully
   * settled before recovery even runs, rather than possibly bit-banging a
   * still-powering-up device. No self-reset this time — that part was
   * tested and confirmed to add nothing (a reset can't affect an external
   * slave's state either way), so it's not worth the extra boot time. */

  /* USER CODE END Init */

  /* Configure the system clock */
  SystemClock_Config();

  /* USER CODE BEGIN SysInit */
  if (__HAL_RCC_GET_FLAG(RCC_FLAG_PORRST) || __HAL_RCC_GET_FLAG(RCC_FLAG_BORRST))
  {
      HAL_Delay(3000);
  }
  __HAL_RCC_CLEAR_RESET_FLAGS();

  /* Must run before MX_I2C1_Init() (further down) ever reconfigures
   * PB6/PB7 into I2C alternate-function mode. */
  _I2C1_BusRecovery();
  /* USER CODE END SysInit */

  /* Initialize all configured peripherals */
  MX_GPIO_Init();
  MX_DMA_Init();
  MX_I2C1_Init();
  MX_TIM2_Init();
  MX_TIM3_Init();
  MX_USART1_UART_Init();
  MX_TIM5_Init();
  MX_TIM1_Init();
  MX_USART2_UART_Init();
  /* USER CODE BEGIN 2 */
  Motor_Init();
  Encoder_Init();
  IBUS_Init();
  RPiLink_Init();
  ADS1115_Init();
  Actuator_Init();
  SteerPID_Init(&steer_pid, KP_STEER, KI_STEER, KD_STEER);
  WheelPID_Init(&wheel_pid_L, KP_WHEEL, KI_WHEEL);
  WheelPID_Init(&wheel_pid_R, KP_WHEEL, KI_WHEEL);
  Motor_Energize();               /* auto-arm on boot, contactor click = system ready */
  last_contactor_ts = TIM5->CNT; /* debounce timer starts from this moment */
  prev_loop_ts      = TIM5->CNT;
  /* USER CODE END 2 */

  /* Infinite loop */
  /* USER CODE BEGIN WHILE */
  while (1)
  {
    /* USER CODE END WHILE */

    /* USER CODE BEGIN 3 */

    uint32_t t0 = TIM5->CNT;

    /* ── 1. Read RC receiver ────────────────────────────────────────────── */
    IBUSData_t rc;
    IBUS_Read(&rc);

    /* ── 1b. Read RPi autonomous link (Phase 5) ─────────────────────────── */
    RPiCmd_t rpi_cmd;
    RPiLink_Read(&rpi_cmd);

    /* ── 2. Contactor edge-detect + 500 ms debounce ─────────────────────── */
    uint8_t rising  =  rc.swd_on && !prev_swd_on;
    uint8_t falling = !rc.swd_on &&  prev_swd_on;

    if (rising || falling)
    {
        uint32_t elapsed = TIM5->CNT - last_contactor_ts;
        if (elapsed >= CONTACTOR_DEBOUNCE_US)
        {
            if (rising)  Motor_Energize();
            else         { Motor_Stop(); Motor_Deenergize(); }
            last_contactor_ts = TIM5->CNT;
        }
    }
    prev_swd_on = rc.swd_on;

    /* ── 3. Time elapsed for PID (µs from TIM5) ─────────────────────────── */
    uint32_t now_ts = TIM5->CNT;
    float dt_s = (float)(now_ts - prev_loop_ts) / 1000000.0f;
    prev_loop_ts = now_ts;

    /* ── 4. Read steering potentiometer feedback via ADS1115 ────────────── */
    ADS1115_Read(&steer);

    /* ── 5. Ackermann motion pipeline & electronic differential ──────────── */
    AckResult_t ack;

    if (Motor_IsArmed() && rc.rc_ok)
    {
        if (rc.auto_mode)
        {
            /* SWB = AUTO: command source is the RPi UART link, gated on its
             * own health independent of the RC iBUS link (rc.rc_ok only
             * tells us SWB's own position is fresh, not whether the RPi is
             * alive). Link loss while AUTO is selected -> brake, same
             * failsafe class as RC loss — see architecture.md §3.5. */
            if (rpi_cmd.link_ok)
            {
                Ackermann_RunAuto(rpi_cmd.steer_target_deg, rpi_cmd.speed_target_ms,
                                  steer.delta,
                                  Encoder_GetRPM_L(), Encoder_GetRPM_R(), dt_s,
                                  &wheel_pid_L, &wheel_pid_R, &ack);
            }
            else
            {
                WheelPID_Reset(&wheel_pid_L);
                WheelPID_Reset(&wheel_pid_R);
                ack.state            = ACK_STATE_BRAKE;
                ack.target_steer_deg = 0.0f;
                ack.V_base            = 0.0f;
                ack.rpm_L             = 0.0f;
                ack.rpm_R             = 0.0f;
                ack.dac_L             = 0U;
                ack.dac_R             = 0U;
            }
        }
        else
        {
            Ackermann_Run(rc.Xn, rc.Yn,
                          rc.fwd_speed_pct, rc.rev_speed_pct,
                          steer.delta, rc.rc_ok,
                          Encoder_GetRPM_L(), Encoder_GetRPM_R(), dt_s,
                          &wheel_pid_L, &wheel_pid_R, &ack);
        }
    }
    else
    {
        WheelPID_Reset(&wheel_pid_L);
        WheelPID_Reset(&wheel_pid_R);
        ack.state            = Motor_IsArmed() ? ACK_STATE_NO_SIGNAL : ACK_STATE_DISARMED;
        ack.target_steer_deg = 0.0f;
        ack.rpm_L            = 0.0f;
        ack.rpm_R            = 0.0f;
        ack.dac_L            = 0U;
        ack.dac_R            = 0U;
    }

    /* ── 6. Steering actuator closed-loop control ──────────────────────────
     * Two-zone control: BANG-BANG (100% speed) while |error| > STEER_PROP_ZONE_DEG,
     * PID (steer_pid.c, previously dead code) once inside that zone — full speed
     * gets the actuator to the neighborhood fast, PID brings it in gently instead
     * of slamming into the deadband at 100% every time (that abrupt stop is what
     * produced the ~4.3-4.5 deg approach-direction hysteresis measured in the
     * field — see scratchpad.md). ACT_MIN_DUTY_PCT floors the PID's output like
     * THR_FWD_MIN_DAC does for the rear wheels, so it can't command a duty too
     * small to break the actuator's own static friction and stall short.
     *
     * "Centered" (stop) condition: when the TARGET is near zero (returning to
     * straight — the case that actually drives the field drift), require BOTH
     * angle_L and angle_R individually within STEER_DEADBAND_DEG, not just their
     * average (steer.delta) — a plain average can read "centered" while the two
     * wheels individually disagree, which is exactly what averaging was hiding
     * (see scratchpad.md). Off-center targets keep the original delta-only
     * check, since angle_L/angle_R legitimately diverge during a real turn
     * (Ackermann inner/outer geometry) and requiring both to match a single
     * target there would be wrong, not stricter.
     *
     * Watchdog: the per-wheel AND-check is only satisfiable if the actual
     * angle_L/angle_R mismatch is under 2*STEER_DEADBAND_DEG — if that ever
     * grows (pot drift, a failing sensor), the PID could hunt forever chasing
     * an unreachable state, and this actuator is only rated for 10% duty cycle
     * (see scratchpad.md's search of the datasheet) — sustained hunting risks
     * cooking it. If the per-wheel check hasn't been satisfied within
     * STEER_CENTER_WATCHDOG_US of continuously trying, fall back to the plain
     * delta-based check (guaranteed satisfiable, since per-wheel-OK always
     * implies delta-OK) so this is guaranteed to terminate either way.
     *
     * Runs on RC validity + sensor health (safe to test with drive unpowered). */
    if (rc.rc_ok && steer.valid)
    {
        float err = ack.target_steer_deg - steer.delta;

        if (fabsf(err) > STEER_PROP_ZONE_DEG)
        {
            /* Positive error (target > actual): drive Left/Extend at 100%
             * Negative error (target < actual): drive Right/Retract at 100% */
            Actuator_SetSpeed(100.0f, (uint8_t)(err > 0.0f));
            SteerPID_Reset(&steer_pid);
            center_watchdog_active = 0U;
        }
        else
        {
            uint8_t targeting_center = (fabsf(ack.target_steer_deg) < CENTER_TARGET_EPS);
            uint8_t centered;

            if (targeting_center)
            {
                if (!center_watchdog_active)
                {
                    center_watchdog_active   = 1U;
                    center_watchdog_start_ts = TIM5->CNT;
                }

                uint8_t per_wheel_ok = (fabsf(steer.angle_L) <= STEER_DEADBAND_DEG) &&
                                       (fabsf(steer.angle_R) <= STEER_DEADBAND_DEG);
                uint32_t elapsed_us = TIM5->CNT - center_watchdog_start_ts;

                if (per_wheel_ok || elapsed_us > STEER_CENTER_WATCHDOG_US)
                {
                    /* Either genuinely centered on both wheels, or the
                     * watchdog gave up waiting for that — fall back to the
                     * plain averaged-delta check either way (always
                     * satisfiable, and already true if per_wheel_ok is). */
                    centered = (fabsf(err) <= STEER_DEADBAND_DEG);
                }
                else
                {
                    centered = 0U;  /* still within budget, keep insisting on both wheels */
                }
            }
            else
            {
                center_watchdog_active = 0U;
                centered = (fabsf(err) <= STEER_DEADBAND_DEG);
            }

            if (centered)
            {
                Actuator_Stop();
                SteerPID_Reset(&steer_pid);
                center_watchdog_active = 0U;
            }
            else
            {
                float duty = SteerPID_Update(&steer_pid, ack.target_steer_deg,
                                             steer.delta, dt_s, NULL);
                if (fabsf(duty) > 0.0f && fabsf(duty) < ACT_MIN_DUTY_PCT)
                    duty = (duty >= 0.0f) ? ACT_MIN_DUTY_PCT : -ACT_MIN_DUTY_PCT;
                Actuator_SetSpeed(fabsf(duty), (uint8_t)(duty > 0.0f));
            }
        }
    }
    else
    {
        Actuator_Stop();
        SteerPID_Reset(&steer_pid);
        center_watchdog_active = 0U;
    }

    /* ── 7. Drive rear motors ────────────────────────────────────────────── */
    uint8_t is_rev = (ack.state == ACK_STATE_REV      ||
                      ack.state == ACK_STATE_REV_LEFT  ||
                      ack.state == ACK_STATE_REV_RIGHT);

    switch (ack.state)
    {
        case ACK_STATE_BRAKE:
        case ACK_STATE_NO_SIGNAL:
            Motor_Brake();
            Motor_SetWasReversing(0U);
            break;

        case ACK_STATE_DISARMED:
            Motor_Stop();
            Motor_SetWasReversing(0U);
            break;

        default:
            if (is_rev && !Motor_WasReversing())
                Motor_BrakeThenReverse(ack.rpm_L, ack.rpm_R,
                                       ack.dac_L, ack.dac_R);
            else
                Motor_SetSpeeds(ack.rpm_L, ack.rpm_R,
                                ack.dac_L, ack.dac_R);
            break;
    }

    /* ── 8. Update encoder RPM ───────────────────────────────────────────── */
    Encoder_Update();

    /* ── 8b. Send feedback frame to the RPi over USART2, every tick (20 Hz) ─
     * Phase 5: lets the RPi's guidance loop see measured steering angle and
     * wheel RPM regardless of which mode (MANUAL/AUTO) is currently active,
     * so it can track state and be ready the instant SWB flips to AUTO. */
    {
        uint8_t status = 0U;
        if (Motor_IsArmed())    status |= RPI_STATUS_ARMED;
        if (!steer.valid)       status |= RPI_STATUS_STEER_FAULT;
        if (rc.auto_mode)       status |= RPI_STATUS_AUTO_ACTIVE;
        if (rc.rc_ok)           status |= RPI_STATUS_RC_OK;

        RPiLink_SendFeedback(steer.angle_L, steer.angle_R,
                             Encoder_GetRPM_L(), Encoder_GetRPM_R(), status);
    }

    /* ── 9. Debug telemetry over USART1 TX → ESP32, rate-limited to ~4 Hz ─── */
    static uint8_t dbg_div = 0U;
    if (++dbg_div >= 5U)
    {
        dbg_div = 0U;
        char cl[12], cr[12], el[12], er[12], ts[12], as[12], line[160];
        _FmtRpm(cl, sizeof cl, ack.rpm_L);
        _FmtRpm(cr, sizeof cr, ack.rpm_R);
        _FmtRpm(el, sizeof el, Encoder_GetRPM_L());
        _FmtRpm(er, sizeof er, Encoder_GetRPM_R());
        _FmtRpm(ts, sizeof ts, ack.target_steer_deg);
        _FmtRpm(as, sizeof as, steer.delta);
        snprintf(line, sizeof line,
                 "STR tgt%s act%s dty%+4d %s | CMD L%s R%s | ENC L%s R%s\r\n",
                 ts, as, (int)Actuator_GetDuty(),
                 steer.valid ? "OK " : "ERR",
                 cl, cr, el, er);
        _DbgPuts(line);
    }

    /* ── 10. Rate-limit to LOOP_HZ (busy-wait on TIM5) ──────────────────── */
    while ((TIM5->CNT - t0) < LOOP_PERIOD_US) {}

  }
  /* USER CODE END 3 */
}

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


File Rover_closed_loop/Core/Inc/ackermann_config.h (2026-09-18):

/* ============================================================================
 *  ackermann_config.h — Ackermann front-steering configuration
 * ============================================================================
 *
 *  This header is ADDITIVE. It does not replace Core/Inc/config.h — the
 *  existing rover geometry, iBUS map, DAC addresses and timing constants all
 *  still come from there. Include BOTH.
 *
 *  ── SIGN CONVENTION (memorise this; every module below depends on it) ──
 *
 *      LEFT turn  = POSITIVE steering angle (+)
 *      RIGHT turn = NEGATIVE steering angle (-)
 *
 *      Joystick Xn > 0 (stick RIGHT) → target_steer NEGATIVE → right turn
 *      Joystick Xn < 0 (stick LEFT)  → target_steer POSITIVE → left  turn
 *
 *      ADC: ADC_*_MIN_RAW corresponds to full RIGHT lock (-MAX_STEER_ANGLE)
 *           ADC_*_MAX_RAW corresponds to full LEFT  lock (+MAX_STEER_ANGLE)
 *
 *      Kinematics: delta > 0 (left turn) → right wheel is OUTER → faster.
 * ============================================================================
 */

#ifndef ACKERMANN_CONFIG_H
#define ACKERMANN_CONFIG_H

#include "config.h"
#include <math.h>

#ifndef M_PI
#define M_PI                    3.14159265358979323846f
#endif

/* ── Chassis geometry ───────────────────────────────────────────────────── */
#define ACK_WHEELBASE_M         0.80f   /* Wb — front axle to rear axle (m)  */
#define ACK_TRACK_M             0.65f   /* Lt — left to right wheel      (m) */

/* ── Steering limits & deadband ─────────────────────────────────────────── */
#define MAX_STEER_ANGLE_DEG     45.0f   /* Max physical steering lock (deg)  */
/* Narrowed 2.5 -> 1.5 deg once the actuator control stopped being pure
 * bang-bang (see STEER_PROP_ZONE_DEG below) — the old value was sized to
 * tolerate bang-bang's abrupt full-speed-until-stop overshoot; the PID
 * zone approaches gently enough that a tighter tolerance is safe to try.
 * Field-verify: if the actuator ever hunts/oscillates right at this
 * boundary, widen it back up before anything else. */
#define STEER_DEADBAND_DEG      1.5f    /* Angular error deadband     (deg)  */
                                        /* (Within ±1.5°, actuator stops/holds) */

/* Below this |angle| the Ackermann equations are treated as "straight" to
 * avoid the tan(delta) singularity at zero.
 * MUST be >= STEER_DEADBAND_DEG. The actuator's bang-bang control can leave
 * the wheels resting anywhere inside +-STEER_DEADBAND_DEG of a commanded
 * angle (it stops correcting once error is that small) — if this threshold
 * were narrower than the actuator's deadband, a residual angle the actuator
 * considers "close enough to straight" could still be wide enough to make
 * Ackermann_ComputeRPM() apply a real (if small) L/R speed differential,
 * causing the rover to drift consistently toward whichever side the
 * actuator happens to rest on when commanded straight. (Diagnosed on
 * hardware: persistent left drift on a "straight" command, actuator resting
 * within its old 1.0 deg window's blind spot — see scratchpad.md.)        */
#define ACK_STRAIGHT_DEG        3.0f

/* ── Steering PID gains (from the BBB config.py port — UNTUNED on this
 * chassis, and now genuinely live: main.c's actuator control (step 6) uses
 * bang-bang beyond STEER_PROP_ZONE_DEG, then hands off to SteerPID_Update()
 * inside it, replacing the old pure-bang-bang-to-stop behavior that
 * produced the field-measured ~4.3-4.5 deg approach-direction hysteresis
 * (see scratchpad.md). These gains were ported from the BBB project and
 * have NEVER been exercised on this hardware before — expect to retune in
 * the field, same as every other gain in this project so far. */
#define KP_STEER                5.0f
#define KI_STEER                0.1f
#define KD_STEER                0.5f

/* Integral anti-windup: clamp so the integral term alone cannot exceed this
 * many percent of duty cycle. */
#define STEER_INTEGRAL_MAX_PCT  50.0f

/* ── Actuator two-zone control (main.c step 6) ──────────────────────────────
 * |error| > STEER_PROP_ZONE_DEG: bang-bang at 100% (unchanged, fast approach).
 * |error| <= STEER_PROP_ZONE_DEG: hand off to steer_pid.c instead of running
 * bang-bang all the way to the deadband — the abrupt full-speed stop is what
 * produced the measured hysteresis. */
#define STEER_PROP_ZONE_DEG     4.0f
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

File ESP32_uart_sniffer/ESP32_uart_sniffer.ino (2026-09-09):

/* ============================================================================
 *  ESP32_uart_sniffer.ino — passive listener for the STM32 -> RPi feedback
 *  link, used to verify the physical/electrical UART connection independent
 *  of the RPi software stack.
 * ============================================================================
 *
 *  WIRING — READ-ONLY TAP, ONE WAY ONLY:
 *      STM32 PA2 (USART2_TX)  ->  ESP32 GPIO16 (RX2)
 *      STM32 GND              ->  ESP32 GND
 *
 *  Do NOT connect anything to STM32 PA3 (USART2_RX) while the RPi is also
 *  wired to it. PA3 is a single wire — if both the RPi's TX pin and this
 *  ESP32's TX pin drive it at once, both boards' UART transmitters fight
 *  each other electrically. This sketch's own TX pin (GPIO17) is configured
 *  in software but deliberately left UNCONNECTED — this is a listen-only
 *  tap, exactly the same one-way-bridge safety rule already used for the
 *  PA9 debug telemetry link elsewhere in this project (see Rover_study.md
 *  §2.7: "the bridge is deliberately one-way").
 *
 *  WHAT THIS PROVES: whether the STM32 is actually putting feedback frames
 *  out on PA2 at all — i.e. the electrical/physical link, completely
 *  independent of the RPi's Python code, its serial port config, or
 *  anything else on that side. If frames show up here but check_stm32_link.py
 *  on the RPi still sees nothing, the problem is specifically on the RPi
 *  side (wiring into the Pi's header, or the Pi's own UART config) rather
 *  than the STM32. If NOTHING shows up here either, the problem is on the
 *  STM32 side or the STM32-to-tap-point wiring itself.
 *
 *  Frame format — MUST stay identical to Rover_closed_loop/Core/Src/rpi_link.c's
 *  header comment and RPi_companion/uart_link.py. No shared schema file
 *  between the three; keep all in sync by hand if the protocol ever changes.
 *
 *  Feedback frame, STM32 -> RPi (and now -> this sniffer), 12 bytes, LE:
 *      [0]     0xBB                    header
 *      [1]     0x66                    header
 *      [2..3]  int16  angle_L          degrees x100
 *      [4..5]  int16  angle_R          degrees x100
 *      [6..7]  int16  rpm_L            RPM x10
 *      [8..9]  int16  rpm_R            RPM x10
 *      [10]    uint8  status           bitfield, see STATUS_* below
 *      [11]    uint8  checksum         XOR of bytes [0..10]
 *
 *  Board: any ESP32 Dev Module. Arduino IDE, no extra libraries needed.
 *  Open the Serial Monitor at 115200 baud after uploading.
 * ============================================================================
 */

#include <HardwareSerial.h>

// UART2 on the ESP32 — GPIO16 = RX2, GPIO17 = TX2 (TX left unconnected, see
// the wiring note above; WROVER boards use GPIO16/17 for PSRAM, use e.g.
// GPIO25/26 instead there — see Rover_study.md §10.4's identical caveat for
// the existing PA9 debug bridge).
#define STM32_RX_PIN 16
#define STM32_TX_PIN 17
#define STM32_BAUD   115200

HardwareSerial STM32Serial(2);

static const uint8_t FEEDBACK_FRAME_LEN = 12;
static const uint8_t HDR0 = 0xBB;
static const uint8_t HDR1 = 0x66;

#define STATUS_ARMED       (1 << 0)
#define STATUS_STEER_FAULT (1 << 1)
#define STATUS_AUTO_ACTIVE (1 << 2)
#define STATUS_RC_OK       (1 << 3)

uint8_t buf[64];
uint8_t buf_len = 0;

uint32_t frames_ok = 0;
uint32_t frames_bad = 0;
uint32_t t_start = 0;
uint32_t t_last_print = 0;
uint32_t t_last_frame = 0;

uint8_t checksum(const uint8_t *b, uint8_t len) {
  uint8_t x = 0;
  for (uint8_t i = 0; i < len; i++) x ^= b[i];
  return x;
}

void handleFrame(const uint8_t *f) {
  int16_t angle_L = (int16_t)(f[2] | (f[3] << 8));
  int16_t angle_R = (int16_t)(f[4] | (f[5] << 8));
  int16_t rpm_L   = (int16_t)(f[6] | (f[7] << 8));
  int16_t rpm_R   = (int16_t)(f[8] | (f[9] << 8));
  uint8_t status  = f[10];

  frames_ok++;
  t_last_frame = millis();

  Serial.printf(
    "OK  angleL=%+6.2f angleR=%+6.2f | rpmL=%+6.1f rpmR=%+6.1f | "
    "ARMED=%d STEER_FAULT=%d AUTO_ACTIVE=%d RC_OK=%d\n",
    angle_L / 100.0, angle_R / 100.0, rpm_L / 10.0, rpm_R / 10.0,
    (status & STATUS_ARMED) ? 1 : 0,
    (status & STATUS_STEER_FAULT) ? 1 : 0,
    (status & STATUS_AUTO_ACTIVE) ? 1 : 0,
    (status & STATUS_RC_OK) ? 1 : 0
  );
}

void setup() {
  Serial.begin(115200);
  delay(200);
  Serial.println();
  Serial.println("[Sniffer] ESP32 UART sniffer for STM32 PA2 (USART2_TX) feedback frames.");
  Serial.println("[Sniffer] Wiring: STM32 PA2 -> ESP32 GPIO16, STM32 GND -> ESP32 GND.");
  Serial.println("[Sniffer] PA3 must stay disconnected from this board — see header comment.");
  Serial.println();

  STM32Serial.begin(STM32_BAUD, SERIAL_8N1, STM32_RX_PIN, STM32_TX_PIN);
  t_start = millis();
  t_last_print = t_start;
}

void loop() {
  // Pull in whatever bytes are available, append to our small buffer.
  while (STM32Serial.available() && buf_len < sizeof(buf)) {
    buf[buf_len++] = (uint8_t)STM32Serial.read();
  }

  // Scan for a complete, valid frame anywhere in the buffer, resyncing
  // byte-by-byte on a checksum mismatch (no IDLE-line hardware framing
  // available on this side, same approach as uart_link.py on the RPi).
  bool progressed = true;
  while (progressed) {
    progressed = false;

    // Find header
    uint8_t start = 0xFF;
    for (uint8_t i = 0; i + 1 < buf_len; i++) {
      if (buf[i] == HDR0 && buf[i + 1] == HDR1) { start = i; break; }
    }

    if (start == 0xFF) {
      // No header found — keep only the last byte in case it's a split header.
      if (buf_len > 1) { buf[0] = buf[buf_len - 1]; buf_len = 1; }
      break;
    }

    if (start > 0) {
      // Drop garbage before the header.
      memmove(buf, buf + start, buf_len - start);
      buf_len -= start;
      progressed = true;
      continue;
    }

    if (buf_len < FEEDBACK_FRAME_LEN) break;  // wait for more bytes

    if (checksum(buf, FEEDBACK_FRAME_LEN - 1) == buf[FEEDBACK_FRAME_LEN - 1]) {
      handleFrame(buf);
      memmove(buf, buf + FEEDBACK_FRAME_LEN, buf_len - FEEDBACK_FRAME_LEN);
      buf_len -= FEEDBACK_FRAME_LEN;
    } else {
      frames_bad++;
      memmove(buf, buf + 2, buf_len - 2);  // drop just the header, keep scanning
      buf_len -= 2;
    }
    progressed = true;
  }

  // Periodic status line, especially useful while nothing is arriving.
  uint32_t now = millis();
  if (now - t_last_print >= 1000) {
    t_last_print = now;
    float elapsed_s = (now - t_start) / 1000.0;
    float rate = frames_ok / elapsed_s;
    uint32_t since_last = t_last_frame ? (now - t_last_frame) : 0;
    Serial.printf(
      "[Sniffer] t=%.1fs  frames_ok=%lu  frames_bad=%lu  rate=%.1f/s  "
      "last_frame=%lums ago  %s\n",
      elapsed_s, frames_ok, frames_bad, rate, since_last,
      frames_ok == 0 ? "-- NOTHING RECEIVED YET --" : ""
    );
  }
}

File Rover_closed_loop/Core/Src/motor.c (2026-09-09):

#include "motor.h"
#include "config.h"
#include "main.h"
#include <stdint.h>

/* ── External HAL handle ──────────────────────────────────────────────────── */
extern I2C_HandleTypeDef hi2c1;
extern TIM_HandleTypeDef htim5;

/* ── Internal state ──────────────────────────────────────────────────────── */
static uint8_t armed         = 0;
static uint8_t is_energized  = 0;
static uint8_t was_reversing = 0;
static uint8_t last_dir_l    = 0;   /* 0 = forward, 1 = reverse */
static uint8_t last_dir_r    = 0;


/* ── Private helpers ─────────────────────────────────────────────────────── */

/* Diagnostic LED — PC13, onboard LED on this Black Pill, active-LOW.
 * Confirmed unused elsewhere in the project. Lights and STAYS lit if the
 * firmware ever refuses to close the contactor because it could not
 * confirm the DACs were at zero throttle (see _EnsureDacsZeroed()).
 * LED lit + no contactor click = the DAC/I2C path is broken, and the
 * firmware deliberately did not energise. */
static void _DiagLedInit(void)
{
    __HAL_RCC_GPIOC_CLK_ENABLE();
    GPIO_InitTypeDef gpio = {0};
    gpio.Pin   = GPIO_PIN_13;
    gpio.Mode  = GPIO_MODE_OUTPUT_PP;
    gpio.Pull  = GPIO_NOPULL;
    gpio.Speed = GPIO_SPEED_FREQ_LOW;
    HAL_GPIO_Init(GPIOC, &gpio);
    HAL_GPIO_WritePin(GPIOC, GPIO_PIN_13, GPIO_PIN_SET); /* off */
}

static inline void _DiagLedOn(void)
{
    HAL_GPIO_WritePin(GPIOC, GPIO_PIN_13, GPIO_PIN_RESET);
}

static inline void _DiagLedOff(void)
{
    HAL_GPIO_WritePin(GPIOC, GPIO_PIN_13, GPIO_PIN_SET);
}
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

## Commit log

2026-09-09 Initial commit: Autonomous Ackermann rover project
    Baseline snapshot covering everything built so far:
    - Rover_closed_loop/: STM32F411 closed-loop Ackermann steering firmware
    (ADS1115 steering feedback, linear actuator control, electronic
    differential, RC iBUS input, and the new Phase 5 RPi UART link on
    USART2/PA2-PA3 with MANUAL/AUTO mode select via SWB)
    - RPi_companion/: Raspberry Pi 5 companion-computer code — STM32 UART
    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
    [RTK_data_1.csv, RTK_data_2.csv, RTK_data_3.csv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]
2026-09-09 docs: record GitHub backup setup and ongoing commit/push workflow
    - Added §4 Version Control to architecture.md: remote URL, what's
    excluded from git and why, the local gh-CLI install workaround
    (no sudo on this dev laptop), and the going-forward workflow
    (commit with an explanatory message + push after each change).
    - works.md: gh auth login succeeding doesn't wire itself into git's
    credential helper — gh auth setup-git is a separate required step,
    hit and fixed during this setup.
    Claude-Session: https://claude.ai/code/session_01Xqi8QbgxqJaDbaoVZjLPoA
2026-09-09 docs: port RPi<->STM32 interconnection into Rover_study.md (§14)
    Rover_study.md is the settled "complete technical reference" document
    (distinct from architecture.md, which is the working/build-log doc
    this whole Phase 5 effort has been tracked in). Now that the UART
    link and IMU are both hardware-verified, folded the interconnection
    into Rover_study.md as a new, clearly-scoped §14:
    - Added a prominent top-of-document note: §14 describes
    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
2026-09-10 Add RPi guidance stack: dead-reckoning odometry + Pure Pursuit
    Built after studying Old_files/dev_bak/'s BBB-era encoder+IMU-only
    autonomous scripts and an explicit design discussion with the user
    (coordinate frame, algorithm choice, every tunable parameter decided
    in conversation before writing any code — see architecture.md §3.9
    and scratchpad.md for the full reasoning).
    - RPi_companion/rover_config.py: shared tunables, mirrors the STM32
    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
2026-09-10 Add mission.py — runnable entry point for the guidance stack
    Ties waypoints.py/odometry.py/guidance.py/uart_link.py/imu.py together
    into an actual runnable autonomous test (everything before this was
    library modules with no program to run).
    - CLI: --pattern straight/rectangle/circle/lawnmower with shape args,
    or --csv <file> to load a previously generated/saved path.
    - Per-run CSV logging (pose, commands, encoder/steering feedback,
    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
2026-09-10 Update steering pot calibration — both potentiometers replaced
    User replaced both steering potentiometers (previously only the left
    one had been) and supplied fresh raw ADC values directly:
    full right: raw_L=3096, raw_R=2124
    full left: raw_L=5793, raw_R=4160
    center: raw_L=4426, raw_R=3167
    Updated ADC_L/R_MIN_RAW, ADC_L/R_MAX_RAW, ADC_L/R_CENTER_RAW in
    ackermann_config.h to these values. The existing 3-point piecewise-
    linear calibration scheme (_MapToAngle() in ads1115.c) needed no code
    changes, only new inputs. Updated the adjacent comment block too,
    which had gone stale across two prior calibration rounds.
    Spans are well-balanced this time: L split 1330/1367 (~3%), R split
    1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
    [ackermann_config.h]
2026-09-10 Fix: heading reference was re-locking on every mission restart
    Caught while answering the user's clarifying question about the
    (0,0)-on-AUTO-engage semantics: Odometry.reset() was clearing the
    heading reference along with position, and mission.py calls reset()
    on every SWB MANUAL->AUTO rising edge. That meant heading 0 re-locked
    to "whichever way the rover happens to be pointed" on every single
    mission restart -- silently making the design functionally identical
    to "start-relative" (the option explicitly NOT chosen in the design
    discussion) instead of "compass-referenced" (the point of which is a
    pattern keeping the same real-world orientation across repeated test
    runs in one session).
    Fix: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
    [mission.py, odometry.py]
2026-09-10 Auto-archive paths + rich telemetry logging; fix real Pure Pursuit bug
    User asked for (1) generated/loaded paths to always be saved, and
    (2) a comprehensive log with all sensor/telemetry data for plotting
    and tuning.
    - mission.py: every run now auto-saves the path actually used to
    logs/mission_<timestamp>_path.csv, sharing the run's telemetry log
    timestamp for easy pairing. --save-csv remains for additionally
    saving a reusable copy elsewhere.
    - Telemetry log expanded from 15 to 31 columns: added cte_m (signed
    cross-track error -- the actual metric the old BBB/RTK systems'
    gains were tuned against), alpha_deg, lookahead_x/y_m, target_idx,
    mission_finished (from guidance.PurePursu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
    [guidance.py, mission.py, odometry.py]
2026-09-11 Fix lookahead regression + rebuild speed law from first AUTO field test
    First-ever SWB=AUTO run diverged ("went straight, later turning").
    Analyzed both logged runs in detail rather than guessing -- found two
    distinct real causes.
    Bug 1 (lookahead search regression): the "search one segment behind
    the cursor" fix from the previous session (for the mission-start
    bug) returned the FIRST valid Ld-circle intersection, not the
    furthest-along one. Near a waypoint-advance boundary the behind-
    segment can have its own valid but BACKWARD intersection -- hand-
    verified on a captured glitch (behind-segment progress 6.02 vs the
    correct forward segment's 7.57), causing single-tick alpha spikes to
    ~-170d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
    [guidance.py, rover_config.py]
2026-09-11 Recalibrate THR_FWD_MIN_DAC from field-measured stiction breakaway
    Discussed 5 more field logs (3 rough/diverging incl. one manually-
    aborted runaway, 2 clean finishes). Central finding: measured wheel
    speed ran ~2.8-3.2x the RPi's commanded speed across every run,
    worse at low commanded speed than at cruise.
    User supplied the missing physical data point: standing-start
    commanded RPM at which the wheels overcome static friction and
    actually start turning = 3.5 RPM.
    Traced the connection: _ToThrottle()'s forward branch in ackermann.c
    linearly maps (0 RPM -> THR_FWD_MIN_DAC) to (WHEEL_RPM_MAX=20 ->
    DAC_MAX=4095). Under the old THR_FWD_MIN_DAC=1100, a commanded
    3.5 RPM produces DAC=1624 -- me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
    [ackermann_config.h]
2026-09-11 Replace open-loop forward throttle map with closed-loop wheel-speed PI
    The THR_FWD_MIN_DAC floor-raise (previous commit) was field-retested and
    made the actual/commanded speed mismatch worse (3.4-5.5x vs 2.8-3.2x) --
    raising a line's intercept while holding its far endpoint fixed lifts the
    whole line, not just the low end. A follow-up empirical regression across
    all 7 field logs (12,724 points) showed the real problem was the map's
    SLOPE (reaches WHEEL_RPM_MAX at DAC~2171, not DAC_MAX), not just its floor.
    Rather than curve-fit a second open-loop map -- which still can't track
    terrain/incline/traction changes in the field -- replaced the whole
    open-loop RPM->DAC guess with closed-loop PI co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
    [ackermann_config.h, main.c]
2026-09-11 Raise WHEEL_RPM_MAX 20->25 (field-measured true motor max)
    MOTOR_RPM_MAX raised 400->500 in config.h -- the 400 RPM figure was the
    motor's datasheet spec, not its real measured max; user field-measured
    the wheels actually reach 25 RPM. WHEEL_RPM_MAX (= MOTOR_RPM_MAX /
    GEAR_RATIO) derives to 25.0 automatically everywhere it's used, including
    Ackermann_ComputeRPM()'s forward RPM ceiling. GEAR_RATIO (mechanical,
    fixed at 20:1) is untouched.
    Source change only. Needs STM32CubeIDE rebuild + reflash before retest.
    Claude-Session: https://claude.ai/code/session_01KksxrTouJN97n5wNTTiUoW
    [config.h]
2026-09-11 Double cruise/min speed after first PID field test
    First field test of the closed-loop wheel PI + 25 RPM ceiling change:
    tracking confirmed excellent once moving (CTE < 7cm, yaw drift < a few
    degrees, both runs), but run 1 sat completely still for 27.6s at mission
    start before breaking free, vs 2.95s in run 2 under identical firmware.
    Root cause: at 0.12 m/s target (~6.5 target RPM), Kp=50's instant
    correction (~325, DAC~1425/35% duty) wasn't enough to break real-world
    static friction on run 1's ground. With the wheel not moving, only the PI
    integral climbed, taking ~23s to hit its clamp and finally supply enough
    DAC (~3675/90% duty) to break free. Terrain friction varied hugely
    between the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
    [rover_config.py]
2026-09-11 Correct misdiagnosis: the "stall" was SWB in MANUAL, not friction
    The previous commit's root-cause analysis (27.6s/2.95s dead-start
    attributed to real-world static friction and slow PI integral wind-up)
    was wrong. User identified the actual cause: SWB was simply still in
    MANUAL for that whole window -- the mission script logs at 20Hz from
    launch regardless of switch position, so the CSV recorded the operator's
    own delay flipping SWB to AUTO, not a stall.
    Verified directly: the auto_active telemetry column (not checked before
    writing the friction analysis) reads 0 for the entire "stall" in both
    runs and flips to 1 only ~150ms before rpm_L/R go nonzero -- a normal,
    fast PI response, not a 20+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
2026-09-11 Average heading-lock samples to fix intermittent one-sided drift
    Read-only analysis of mission_20260911_173125 (and a re-check of the
    previous turn's logs) found a real, distinct issue: cte_m never crosses
    zero for an entire ~186s/20m run, steer_cmd_deg is one sign on every
    nonzero tick (3571/3571) -- a fixed one-directional bias, not noise.
    mission_20260911_165910 shows the identical signature; _170745 (same day,
    same firmware) is clean. Intermittent, and 165910 predates this session's
    wheel-PID/speed work entirely, ruling those out.
    Root cause: Odometry's "straight ahead" reference locked from a SINGLE
    IMU sample at mission start. imu_calib_mag/imu_calib_sys read 0 for the
    entire duration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
    [odometry.py, rover_config.py]
2026-09-11 Add steering-pot recalibration tool for the L/R center mismatch
    Checking angle_L/angle_R specifically at commanded-straight (before any
    turn had been issued -- the one condition where true Ackermann geometry
    says both wheels should agree, since inner/outer divergence only applies
    mid-turn) found a real, repeatable ~1.1-1.6 deg gap in 3 of 4 field logs,
    including the one run that otherwise tracked cleanly. That rules it out
    as the explanation for the intermittent heading-lock drift (a constant
    hardware offset would bias every run equally) but flags it as a real,
    separate bias worth fixing: _MapToAngle() in ads1115.c trusts each
    wheel's ADC_*_CENTER_RAW as exactly 0 deg independently, with no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
    [calibrate_steering_pots.py]
2026-09-15 Rebuild steering actuator control: bang-bang/PID hybrid + per-wheel centering
    Two field calibration runs disagreed on where "center" was by ~2.9 deg.
    Traced to a separate, larger issue: settling to commanded-zero from full-
    left-lock vs. full-right-lock left the wheels ~4.5 deg apart, and
    re-mapping the same raw readings through a freshly-recalibrated pot
    mapping barely changed the gap (4.53 -> 4.29 deg) -- proving this is
    actuator-control hysteresis, not a sensor calibration problem. Root
    cause: main.c's actuator control was pure bang-bang (100% speed, no
    deceleration, stop only once the deadband trips), so overshoot varies
    with approach direction/momentum rather than landing on a fixed poi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
    [ackermann_config.h, main.c]
2026-09-16 Sync Rover_study.md §14 with everything since the RPi link was verified
    This reference doc had not been touched since §14 covered "the
    interconnection is verified but nothing autonomous runs yet" -- a full
    guidance stack, two closed-loop control rewrites, and several rounds of
    field diagnosis have happened since then, none of it folded back in.
    Added:
    - §14.7 Guidance & Motion Stack: odometry.py's heading-lock design (incl.
    the recent averaging fix), guidance.py's Pure Pursuit choice and speed
    shaping, waypoints.py, mission.py, rover_config.py's current speed
    profile, calibrate_steering_pots.py.
    - §14.8 Closed-Loop Wheel-Speed & Steering-Actuator Control: wheel_pid.c
    (forward-on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
2026-09-16 Append dated addenda to stale Documentations/ files, without rewriting them
    Per request: don't rewrite these historical/reference files, just add
    what's changed since, clearly dated and appended below the existing
    content.
    - WorkLog.txt: this log's own scope ends at Session 3 (2026-07-30, the
    BBB->STM32 migration). Appended a pointer to where the continuing
    Rover_closed_loop/RPi_companion work is actually tracked
    (architecture.md/scratchpad.md/works.md) instead of duplicating that
    history here, plus a short milestone summary for orientation.
    - test_guide.txt: the 0.200 m/s speed_mps values throughout were an early
    placeholder, since moved twice (0.2 -> 0.12 -> 0.24, current). Appe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
2026-09-17 Add Documentations/current_rover_status.txt — full live system snapshot
    A new, single-file current-state reference covering everything about
    Rover_closed_loop/ + RPi_companion/ as they stand right now: system
    overview and block diagram, full pin mapping, physical/mechanical specs
    (chassis geometry, motor/gearbox, the steering actuator's identified
    datasheet specs), firmware module map, the main control loop as an ASCII
    flowchart, every control-law equation currently in use (electronic
    differential, steering actuator bang-bang/PID hybrid, wheel-speed PI,
    Pure Pursuit steering + speed shaping, dead-reckoning odometry + circular-
    mean heading lock), the UART protocol frame formats, failsafes,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
2026-09-17 current_rover_status.txt: add the full manual/RC Ackermann pipeline
    The initial version covered the electronic differential generically and
    the RPi/AUTO side in depth, but skipped the complete manual/RC-driven
    Ackermann_Run() state machine -- exactly the "basic to advanced movements"
    flow requested.
    - §5.1 expanded with the exact Xn/Yn stick-to-float mapping (ibus.c's
    _ToFloat(): linear normalize + flat deadband, no curve shaping) and an
    explicit note that pipeline.c/kinematics.c (which DO contain curve-
    shaping constants like EPSILON/MIN_RATIO/SPOT_RPM) are dead code in
    this build -- main.c never calls them.
    - §5.3 (new): the full three-branch Ackermann_Run() state machine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
2026-09-18 Fix actuator wobble at center: ACT_MIN_DUTY_PCT 40->15%
    First hardware flash of the bang-bang/PID actuator redesign: "the linear
    actuator is wobbling at zero position."
    Root cause: ACT_MIN_DUTY_PCT=40% floored ANY nonzero PID correction up to
    40% duty. With STEER_DEADBAND_DEG narrowed to 1.5 deg, even a fractional-
    degree correction snapped up to 40% was enough to overshoot straight back
    out the other side of the deadband every time, triggering the same
    correction in reverse -- a self-sustaining limit-cycle, not the gentle
    creep-to-stop the PID zone was built to provide. Same category of mistake
    as the original THR_FWD_MIN_DAC=1624 guess earlier this session -- an
    unverified starting number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
    [ackermann_config.h]
2026-09-18 Test opposite theory for actuator wobble: ACT_MIN_DUTY_PCT 15->70%
    Wobble at center persisted even after the previous fix (40->15%). User
    proposed the opposite theory: 15% may be below this self-locking-screw
    actuator's real breakaway torque, so it chatters/buzzes in place rather
    than cleanly moving and settling -- instead of 40% (and by extension 15%)
    overshooting the 1.5 deg deadband, as originally diagnosed.
    Raised ACT_MIN_DUTY_PCT to 70 as a direct test of that theory rather than
    a confident fix either way -- the retest result will discriminate between
    the two: if it settles, insufficient torque is confirmed and 70% (or
    near it) is closer to the true floor; if the wobble gets worse/fast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
    [ackermann_config.h]
2026-09-18 Remove actuator duty floor entirely: ACT_MIN_DUTY_PCT -> 0
    Wobble got WORSE at ACT_MIN_DUTY_PCT=70% (not better), decisively ruling
    out the insufficient-breakaway-torque theory and confirming the original
    overshoot theory: any floor of meaningful size relative to the 1.5 deg
    deadband overshoots straight back out on every correction, and a bigger
    floor makes that bigger/faster.
    Set ACT_MIN_DUTY_PCT=0.0f -- the `fabsf(duty) < ACT_MIN_DUTY_PCT` clamp in
    main.c step 6 becomes a true no-op (fabsf() is never negative), so the
    PID's raw computed output now drives the actuator directly, with nothing
    forcing a jump to any minimum.
    Known, explicitly-flagged trade-off: very close to target, the PID's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
    [ackermann_config.h]
2026-10-04 Add comprehensive README, internship report, handover guide, figures, and KiCad PCB hardware files
    [BBB_Mapping.kicad_sch, Mod_1.kicad_sch, RX_Design.kicad_sch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]

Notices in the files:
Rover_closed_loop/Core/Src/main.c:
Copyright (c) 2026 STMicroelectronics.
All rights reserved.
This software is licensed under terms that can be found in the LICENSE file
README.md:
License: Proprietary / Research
